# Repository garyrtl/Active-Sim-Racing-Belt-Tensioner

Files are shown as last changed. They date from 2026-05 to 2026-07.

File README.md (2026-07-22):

# DIY Active Sim Racing Belt Tensioner: Complete Build Guide

https://www.youtube.com/watch?v=jDv2dkZlcOc

## 1. Introduction

**What is an Active Belt Tensioner?**  
In sim racing, a belt tensioner physically pulls your shoulder straps (or a harness) tight during braking and loosens during acceleration, adding a realistic G-force feel. Unlike a static harness, an *active* tensioner uses motors to dynamically adjust tension based on telemetry data from your sim.

**How This Project Works**  
This design uses two **hoverboard motors** driven by an **ODESC (open-source ODrive clone)** controller. The motors wind bicycle brake cables around 3D-printed spools, pulling on your harness straps. The ODESC receives commands from **SimHub** (popular sim racing telemetry software), which interprets game data (G-forces, engine vibration, gear shift kick) to control motor torque.

**Source Repository:** [github.com/garyrtl/Active-Sim-Racing-Belt-Tensioner](https://github.com/garyrtl/Active-Sim-Racing-Belt-Tensioner)

**Discord:** [https://discord.gg/UPYektbab](https://discord.gg/UPYektbab)

---

## 2. Bill of Materials (BOM) with Estimated Costs

| Item | Approx. Cost |
|---|---|
| ODESC 3.6 Dual-drive, 56V version (required for hoverboard motors) | $55 |
| 24V 20A PSU (generic) | $30 |
| 2 used hoverboard motors | $30 |
| 2 SK16 supports | $16 |
| 2 Bicycle brake cables | $5 |
| PETG Filament | $4 |
| 16 M4 20mm bolts | $3 |
| 6 M5 25mm bolts | $2 |
| 6 M5 nuts | $2 |
| 4 M5 or M6 4040 T-nuts | $2 |

> **Cost-Saving Tips:**
> - Buy **used hoverboard motors** from broken hoverboards (often $10–20 each)

---

## 3. Step-by-Step Build Guide

### Step 1: 3D Print the Pulley Spools

- Download `pulley-spool.stl` from the [GitHub repo](https://github.com/garyrtl/Active-Sim-Racing-Belt-Tensioner/blob/main/pulley-spool.stl) or open the [Tinkercad design](https://www.tinkercad.com/things/5T1yV7gz4mY-active-belt-tensioner)
- **Print settings:** 100% infill (for strength), PLA or PETG
- You need **two spools** – one for each shoulder strap

### Step 2: Prepare Hoverboard Motors

- Remove the tire from each hoverboard motor, leaving only the metal hub with the motor windings
- Remove 6 phillip screws from the motor hub. Install the spool to the motor. Fasten spool with 6 x M4 20mm bolts
- You should see **3 thick phase wires** (usually yellow, blue, green) and **5 thin sensor wires** (red, black, and three signal wires)
- Keep the hall sensor wires – the ODESC can use them for smoother control
- Solder or crimp spade connectors onto the phase wires

### Step 3: Wire the Electronics

> ⚠️ **Safety:** 24V at 20A is dangerous. Double-check polarity and use thick wires.

**Power connections:**
- Power supply AC input → wall outlet (with ground)
- Power supply DC output (+24V) → ODESC "PV" terminal (power input)
- Power supply DC output (GND) → ODESC "GND" terminal

**Motor connections (repeat for both motors):**
- ODESC "M0" (U, V, W) → Motor phase wires (any order initially – we'll tune later)
- ODESC "M0 Hall" → Motor hall sensors (match colors if possible, refer to ODrive guide)

**USB:** Connect ODESC to your PC via micro-USB

### Step 4: Mount Motors and Linear Supports

- **Mount SK16 shaft supports** to 4040 aluminum extrusions using M5 or M6 bolts and t-nuts. Mount hoverboard motors to SK16 shaft supports.
  
  **DO NOT** connect bicycle brake cables yet!



### Step 5: Configure ODESC for Hoverboard Motors
  * If ODrive not detected, install USB driver using Zadig
  * Download Zadig: https://zadig.akeo.ie/
  * In Zadig: Options -> List All Devices
  * Select "ODrive 3.6 Native Interface"
  * Install WinUSB driver
1. Install ODrive tools on your PC (Python + odrivetool)
2. Run `odrivetool` and connect to the ODESC
3. Calibrate each motor: 
Follow the [ODrive hoverboard motor guide](https://docs.odriverobotics.com/v/0.5.6/hoverboard.html) but adapt for ODESC:

### Step 6: Assemble the Cable & Spool Mechanism

1. Insert the bicycle brake cable through M5 bolts in the spool
   
2. Attach the other end of the cable to the harness strap anchor bracket.
   

### Step 7: Set Up SimHub (Telemetry to Tensioner)
Download and install SimHub

1. In SimHub, go to Custom Serial Device. Add a new device
2. Click "Import" and select the file belt-tensioner-settings.shsds from the GitHub repo
3. Set Serial Port to the COM port of your ODESC (look for "ODrive 3.6 CDC")

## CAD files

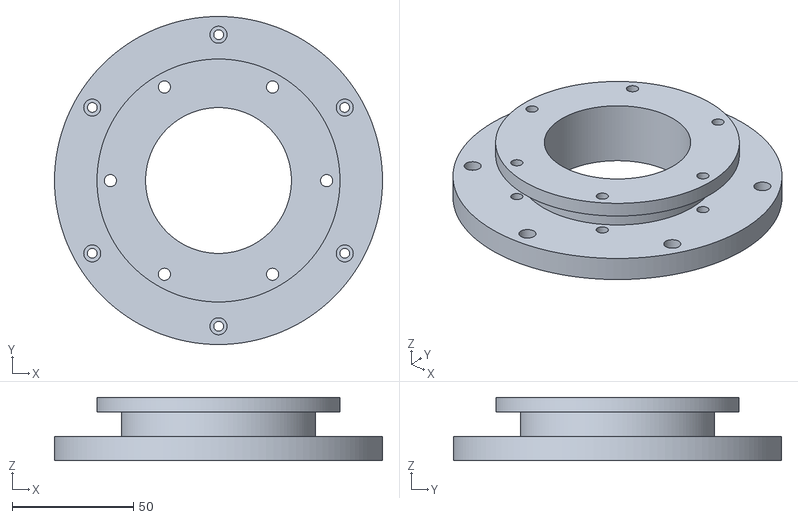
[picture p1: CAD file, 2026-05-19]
pulley-spool.stl
135.0 x 135.0 x 26.0
